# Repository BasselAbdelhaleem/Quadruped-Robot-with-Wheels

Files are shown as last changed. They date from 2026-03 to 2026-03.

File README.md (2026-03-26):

# 🤖 Quadruped-Robot-with-Wheels

> A four-legged robot with mecanum wheels at its feet — combining the terrain adaptability of legged locomotion with the speed and efficiency of wheeled drive.

<div align="center">
  <table style="width: 100%;">
    <tr>
      <td style="width: 60%; vertical-align: top;">
        
      </td>
      <td style="width: 40%; vertical-align: top;">
        
      </td>
    </tr>
  </table>
</div>

---

## 🧠 What Is This?

This is a custom-designed and fabricated quadruped robot that replaces the conventional foot end-effector with **mecanum wheels** — enabling both legged locomotion over uneven terrain and omnidirectional wheeled movement on flat surfaces. The robot is designed to be fully **modular**, with any component replaceable without modification to surrounding parts, making it ideal for research and iterative development.

Inspired by industry platforms like **Swiss-Mile (ETH Zurich)** and **Spot (Boston Dynamics)**, QuadWheel was built from the ground up using accessible materials and manufacturing methods — proving that advanced robot design is achievable outside of well-funded labs.

This project covers the complete hardware lifecycle — from concept and CAD to fabrication, assembly, and embedded low-level motor control.

---

## 🎥 Demo

<table style="width: 100%;">
  <tr>
    <td style="width: 33%; vertical-align: top;">
      <video src="https://github.com/user-attachments/assets/62846b2c-08e2-43ef-a53b-30cdd5eee27c"></video>
    </td>
    <td style="width: 33%; vertical-align: top;">
      <video src="https://github.com/user-attachments/assets/35af5436-f93d-4f27-a48a-da1c4396e53f"></video>
    </td>
    <td style="width: 33%; vertical-align: top;">
      <video src="https://github.com/user-attachments/assets/56d87e05-a18e-4513-a69d-81bef750ae9e"></video>
    </td>
  </tr>
</table>

---

## ✨ Key Features

- **Leg-wheel hybrid locomotion** — mecanum wheels as end-effectors enable both legged walking and omnidirectional rolling
- **Novel knee mechanism** — hip-mounted motor drives the knee via a lead screw, minimizing leg inertia and power consumption
- **3 DOF per leg** — hip abduction/adduction, hip flexion/extension, and knee flexion/extension
- **Incremental encoder feedback** — custom-designed optical encoder wheels on each joint for position and speed sensing
- **Modular architecture** — every subsystem (leg, motor hub, wheel bracket) is independently replaceable
- **Multi-material construction** — aluminum frame and structural links with 3D-printed enclosures and encoder components
- **Low-level stepper motor control** — closed-loop position and speed control via Arduino

---

## 🏗️ System Architecture

```
┌──────────────────────────────────────────────┐
│         HIGH-LEVEL CONTROL  (Future)         │
│   Gait Planning · Navigation · Vision        │
└───────────────────┬──────────────────────────┘
                    │ Serial / Communication
┌───────────────────▼──────────────────────────┐
│        LOW-LEVEL CONTROL  (Arduino)          │
│  Stepper Control · Encoder Feedback · PWM    │
└───────────────────┬──────────────────────────┘
                    │
┌───────────────────▼──────────────────────────┐
│              ACTUATORS & SENSORS             │
│  12× Stepper Motors · Optical Encoders       │
│  4× DC Wheel Motors · Motor Drivers          │
└──────────────────────────────────────────────┘
```

---

## 🔧 Hardware

### Platform Overview

| Property | Value |
|---|---|
| **Locomotion Type** | Leg-Wheel Hybrid |
| **Legs** | 4 |
| **DOF per Leg** | 3 (ab/ad + hip fl/ex + knee fl/ex) |
| **Total Joint Motors** | 12 × NEMA 17 Stepper |
| **Wheel Motors** | 4 × High-RPM DC Motor |
| **End Effector** | 120mm Mecanum Wheel |
| **Total Weight** | ~6 kg |
| **Max Leg Extension** | 665 mm |

### Mechanical Structure

#### Body
The chassis consists of an **aluminum square tube frame** (20mm × 20mm × 2mm wall) providing structural rigidity while keeping weight low. 3D-printed protective plates enclose the body and mount the legs, while a central electronics carriage houses all control hardware behind a removable cover for easy access.

| Body Component | Material | Quantity |
|---|---|---|
| Main frame tubes | Aluminum (2mm wall) | 10 |
| Protective side plates | 3D-printed PLA | 4 |
| Electronics carriage | 3D-printed PLA | 1 |
| Face plates | 3D-printed PLA | 2 |

#### Leg Design

Each leg has five major subsystems:

**1. Hip Joint (ab/ad) — Fixed Motor Hub**
Mounts the leg to the body and enables lateral swing. Houses the optical encoder disk and speed sensor pair.

**2. Hip Joint (fl/ex) — Rotating Motor Hub**
Drives the leg forward and backward. Coupled to the fixed motor hub via a D-shaft coupler, with a bearing support on the body side for smooth, supported rotation.

**3. Knee Mechanism — Lead Screw Drive**
A stepper motor at the hip rotates a lead screw which drives a linear slider along the upper leg. Two connecting plates link the slider to the lower leg, converting linear motion into knee rotation. This design keeps motor mass close to the hip pivot, **minimizing leg inertia** — the same approach used in Spot and Mini Cheetah.

```
Motor (rotation) → Lead Screw → Slider (linear) → Connecting Plates → Knee (rotation)
```

**4. Upper Leg Frame**
Four aluminum plates in a hollow truss pattern — strong under bending but material-efficient. Mounts the linear bearing block (for the slider) and pivots the lower leg.

**5. Lower Leg + Wheel Assembly**
An aluminum rod with a slotted profile that accepts:
- **Wheel bracket** — U-shaped plate holding the mecanum wheel on a bearing-supported rod
- **Wheel motor hub** — Houses a high-RPM DC motor; slides along the slot to tension the drive belt

The wheel motor drives the mecanum wheel via a **pulley-and-belt transmission**, keeping the motor mass on the leg body rather than at the foot — again minimizing rotational inertia.

### Mecanum Wheels

Mecanum wheels replace the conventional foot, providing **two degrees of freedom from a single motor**. By coordinating all four wheels, the robot can move forward, sideways, diagonally, or rotate in place — dramatically improving mobility on flat surfaces.

The wheel design was adapted from an open-source model and modified:
- Diameter scaled from 80mm → **120mm** for the robot's size
- Roller pin diameter changed from 3mm → **5mm** for local availability
- Mounting interface redesigned for belt-driven rod (rather than direct motor shaft)

```
Wheel directions achievable:
  Forward / Backward / Left / Right
  Clockwise / Anticlockwise rotation
  Diagonal movement in all directions
```

### Motor Selection & Gearbox

**Torque analysis (worst-case scenarios):**

| Scenario | Motor | Required Torque |
|---|---|---|
| Lifting leg (COM at knee) | Hip fl/ex | **6.23 Nm** |
| Lifting body with four legs | Knee | 3.5 Nm |
| Carrying body on two legs | Hip ab/ad | 1.91 Nm |

No single off-the-shelf motor available locally met the 6.23 Nm requirement. After evaluating DC, stepper, and brushless options across torque, size, weight, and bidirectional driver availability, **NEMA 17 stepper motors** were selected as the best balance — with a **1:15 planetary gearbox** added to reach the required output torque with a 1.2× safety factor.

| Motor | Max Torque | Speed | Count |
|---|---|---|---|
| NEMA 17 Stepper + 1:15 Gearbox | ~7.5 Nm (output) | — | 12 (joints) |
| High-RPM DC Motor | — | High | 4 (wheels) |

### Encoder Design

Custom **incremental optical encoders** were designed and 3D-printed for each joint motor:

- An encoder disk with **evenly spaced slots** (35mm diameter) mounts on the motor shaft
- Two photoelectric speed sensors are positioned on the disk at a **5° phase offset** to detect both speed and direction of rotation
- The quadrature signal (A/B channels) is read by the Arduino to compute joint position and velocity

This was a deliberate design challenge — servo motors with built-in encoders were intentionally avoided to demonstrate proficiency with raw actuator control.

### Manufacturing Methods

| Process | Applied To |
|---|---|
| **Welding** | Aluminum frame assembly |
| **Laser Cutting** | Side plates, top/bottom plates, connecting plates, encoder disks, wheel bracket |
| **Lathe (turning)** | Slider body, lower leg, wheel bracket neck |
| **Milling** | Slots, holes, flats on lower leg and slider |
| **3D Printing** | Covers, motor hubs, bearing extensions, encoder disks, mecanum rollers |
| **Bending** | Upper leg top/bottom plates, wheel bracket plate |

---

## 💻 Low-Level Control (Arduino)

### Stepper Motor Control

Each of the 12 NEMA 17 stepper motors is driven via a dedicated **stepper motor driver**. The Arduino generates step and direction signals to command precise angular positions.

- **Open-loop stepping** for commanded position targets
- **Closed-loop speed regulation** using encoder feedback to verify actual joint velocity
- Step resolution tunable via microstepping settings on the driver

### Encoder Feedback

The custom incremental encoders produce quadrature (A/B) pulse trains. The Arduino reads these via **interrupt-driven routines** for accurate, low-latency position and velocity estimation:

```cpp
// Quadrature decoding — direction from phase relationship
void encoderISR() {
  int a = digitalRead(ENC_A);
  int b = digitalRead(ENC_B);
  if (a == b) encoderCount++;
  else        encoderCount--;
}
```

Joint angle is tracked by counting encoder pulses and mapping to degrees using the disk's slot count.

### Motor Driver Interfacing

Each stepper driver receives:
- `STEP` — pulse per microstep
- `DIR` — rotation direction
- `EN` — enable/disable motor hold torque

The DC wheel motors are driven via separate motor drivers using PWM speed control and direction pins.

---

## 📐 Kinematics Overview

Each leg has 3 active joints providing a 3D workspace:

| Joint | DOF | Motion |
|---|---|---|
| Hip ab/ad | Rotation about body axis | Swings leg laterally |
| Hip fl/ex | Rotation about transverse axis | Swings leg forward/backward |
| Knee fl/ex | Rotation about transverse axis | Extends/retracts lower leg |

**Creeping gait** (statically stable): legs raised and lowered sequentially — at least 3 legs always on the ground. This is the planned initial gait for higher-level control implementation.

---

## 📁 Repository Structure

```
QuadWheel/
├── cad/
│   ├── body/                   # Body frame, covers, electronics carriage
│   ├── leg/                    # Upper leg, lower leg, slider, connecting plates
│   ├── wheel/                  # Mecanum wheel, bracket, motor hub
│   ├── encoder/                # Encoder disk, motor hub designs
│   └── gearbox/                # Modified 1:15 planetary gearbox
├── code/
│   ├── 2LegControl/            # Full leg control of 2 of the 4 legs
│   ├── CL_Leg_Control/         # Full closed loop leg control
│   └── DC/                     # DC motor control for the wheels
│   └── inverse_kinematics/     # Testing high level control for the leg inverse kinematics
│   └── master_writer/          # Communication between master board and slave boards
├── docs/
│   └── thesis.pdf              # Full design & fabrication documentation
├── engineering_drawings/       # Full dimensioned drawings for all parts
├── media/                      # Photos, videos, demo footage
└── README.md
```

---

## 🚀 Getting Started

### Hardware Requirements

- 12× NEMA 17 Stepper Motor + 1:15 Gearbox
- 12× Stepper Motor Driver (e.g., A4988 or DRV8825)
- 4× High-RPM DC Motor
- 4× DC Motor Driver
- Arduino Mega (recommended for pin count)
- 24× Photoelectric Speed Sensors (2 per joint)
- Custom encoder disks (3D print from `/cad/encoder/`)

### Software Setup

```bash
# Clone the repository
git clone https://github.com/yourusername/QuadWheel.git
cd QuadWheel/arduino

# Open in Arduino IDE
# Upload stepper_control/stepper_control.ino to your Arduino
```

### Running Joint Control

```cpp
// Example: Command hip flexion joint to 45 degrees
setJointAngle(HIP_FLEX_FL, 45.0);

// Example: Read current joint position from encoder
float angle = getJointAngle(HIP_FLEX_FL);
```

---

## 🔮 Future Work

The hardware and low-level firmware provide a solid foundation. Planned next steps:

- **Gait controller** — implement creeping (statically stable) and trotting gaits
- **Inverse kinematics** — foot-space to joint-space mapping for trajectory following
- **High-level autonomy** — integrate a single-board computer (Raspberry Pi / Jetson) for navigation
- **Brushless motor upgrade** — replace steppers with bidirectional brushless motors for higher power density
- **TPU roller replacement** — reprint mecanum wheel rollers in flexible filament for better grip
- **Sensor integration** — add IMU for body orientation, depth camera for terrain perception

---

## 🧩 Skills Demonstrated

| Domain | Demonstrated Skills |
|---|---|
| **Mechanical Design** | 3-DOF leg kinematics, lead-screw knee mechanism, belt-drive transmission, modular assembly |
| **CAD & Engineering Drawing** | Full robot CAD, toleranced engineering drawings for every custom part |
| **Manufacturing** | Welding, laser cutting, CNC lathe, milling, 3D printing — end-to-end fabrication |
| **Embedded Systems** | Arduino stepper control, quadrature encoder decoding, interrupt-driven ISRs |
| **Actuator Selection** | Torque analysis, gear ratio calculation, motor benchmarking under real constraints |
| **System Design** | Modular architecture for research-oriented iterative development |

---

## 📄 Documentation

The full design rationale, torque calculations, material selection, and fabrication process are documented in the thesis paper:

📄 [`docs/thesis.pdf`](docs/thesis.pdf) — *Design and Implementation of Quadruped with Wheels*, GUC Mechatronics Engineering, 2023

---

## 👤 Author

**Bassel Khaled Abdelhaleem**
Mechatronics Engineering — German University in Cairo (GUC)
Supervised by: Assoc. Prof. Dr. Eng. Amir Roushdy

📧 your.email@example.com
🔗 [LinkedIn](https://linkedin.com/in/yourprofile)

---

## 📄 License

This project is licensed under the MIT License — see [LICENSE](LICENSE) for details.

---

<p align="center">
  <i>Designed from scratch. Fabricated by hand. Driven by curiosity.</i>
</p>

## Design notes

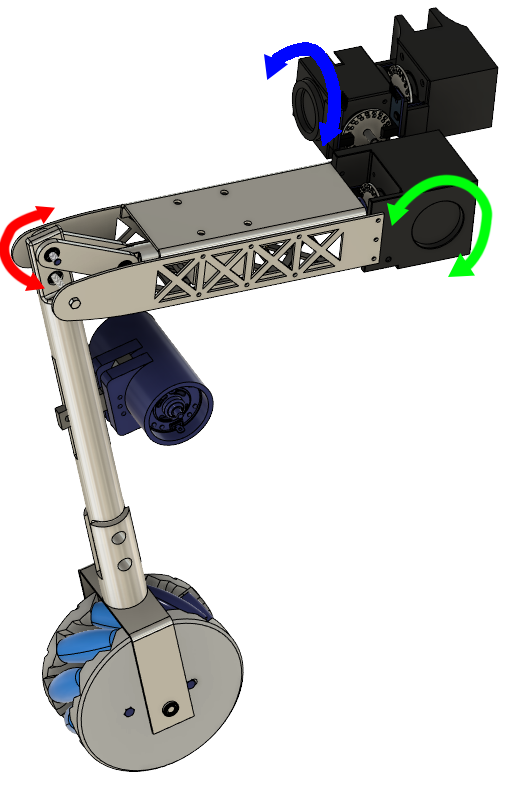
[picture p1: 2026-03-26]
media/Leg Model with motion arrows.png

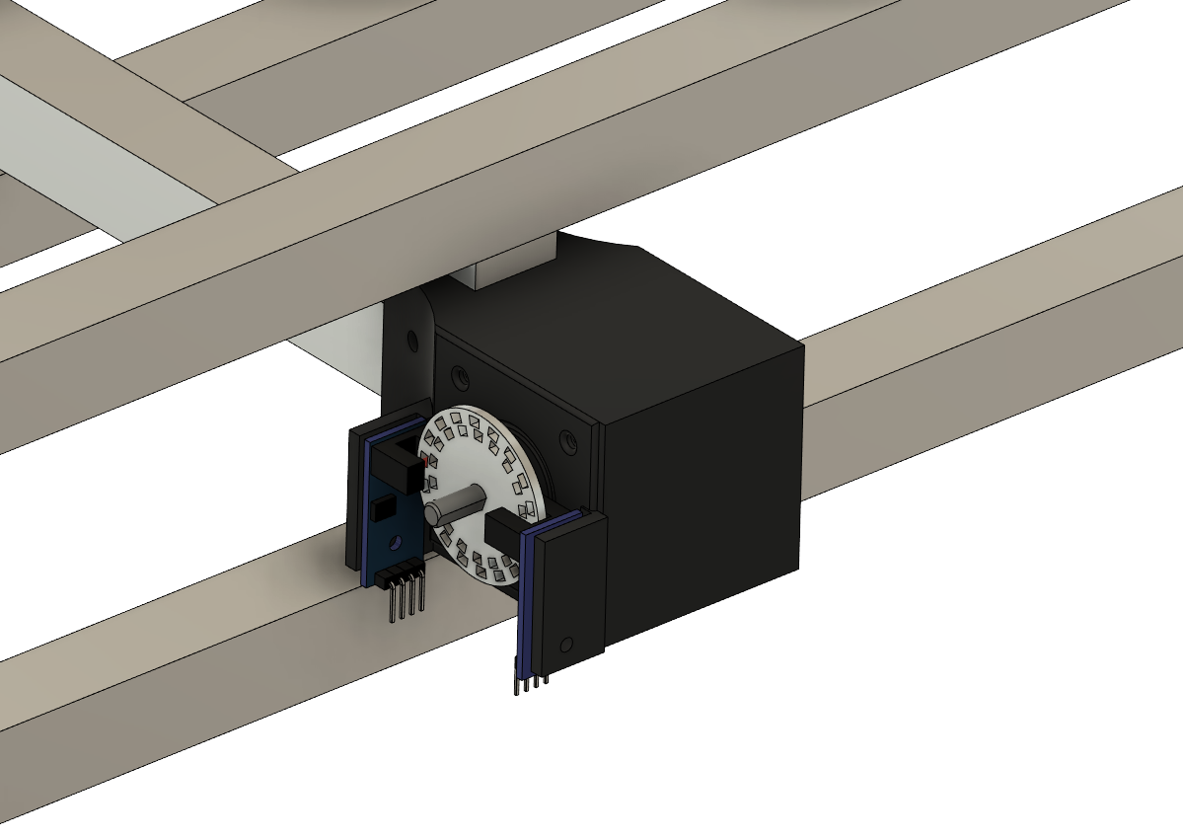
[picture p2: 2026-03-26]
media/Fixed Motor hub on body.png

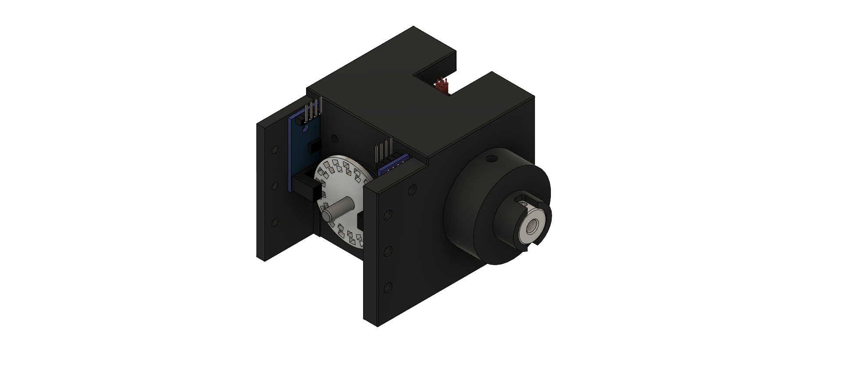
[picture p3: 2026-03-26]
media/Knee Motor Hub new.png

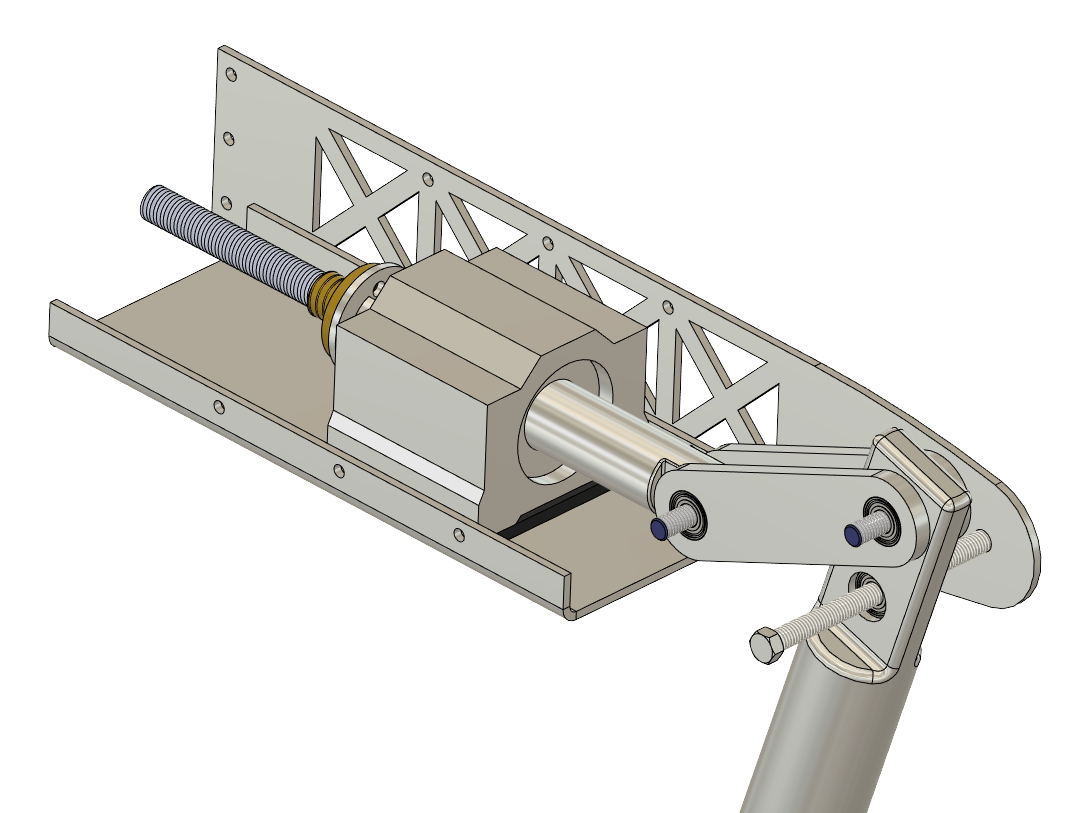
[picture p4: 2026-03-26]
media/Connecting Plates.png

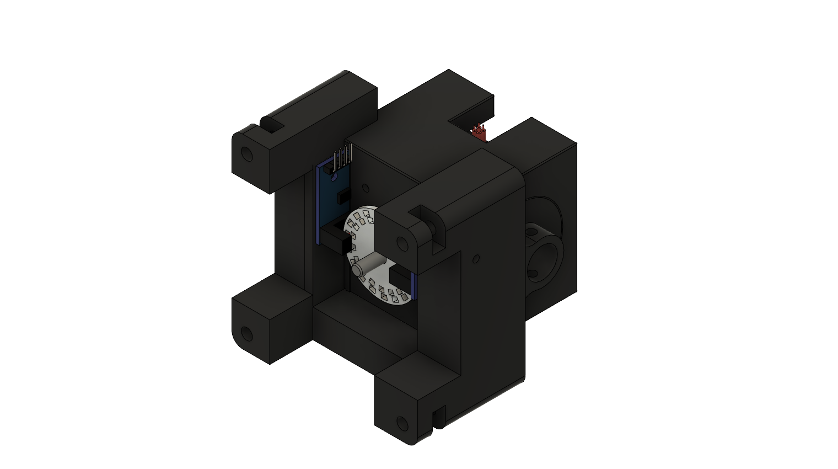
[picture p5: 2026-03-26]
media/Rotating Motor Hub new.png

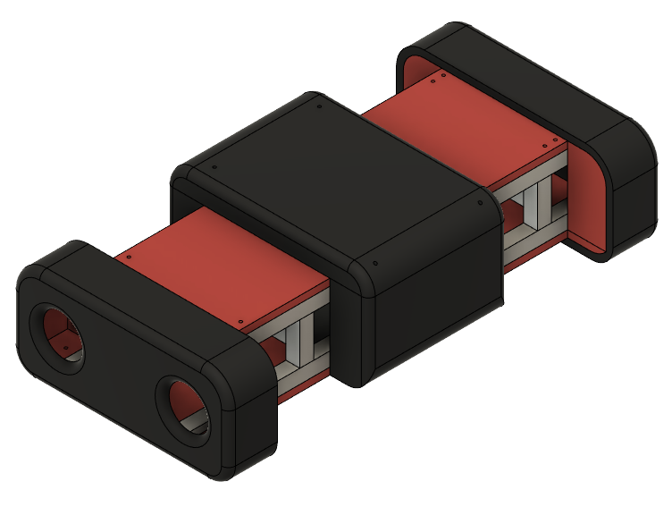
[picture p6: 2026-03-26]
media/Body.png

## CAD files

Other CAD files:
cad/_8-mm lead screw.1c959d5e-ae82-4d65-a514-8b0826073087.f3d
cad/_8mm Lead Screw.d66c99ec-897a-4300-bc53-3debbe2a3609.f3d
cad/_Aluminum Square Tube 140mm.e856f826-5169-4751-9446-e42fab014422.f3d
cad/_Aluminum Square Tube 600mm.9d08fe10-a695-4359-8446-904a571cda24.f3d
cad/_Aluminum Square Tube 60mm.18603a37-9614-456d-951d-5e2553b5a8b8.f3d
cad/_Back Left Leg.a9f00470-0ef0-4690-a3cf-9215a9c23bdc.f3d
cad/_Back Right Leg.691853e6-ca59-419d-a8fc-fe1a00d16451.f3d
cad/_Bearing 61904.1ed075eb-d7d1-4e55-98bb-6b850e03c20e.f3d
cad/_Bearing 628_5-2Z.6bdbf784-737e-40b5-bb04-947494ef0179.f3d
cad/_Body.7ab0c087-588a-4772-b4b6-61f81eb7d17c.f3d
cad/_Coupler 5-8.18f0973a-a07b-4757-b95f-701b0c2533d9.f3d
cad/_Encoder Wheel.eb9523d5-e484-4a40-b553-a28b88c10ead.f3d
cad/_F249 sensor v2.d0049eca-ee8b-4d05-afa8-f4fc4885895e.f3d
cad/_Fixed Motor Hub.4b5598e1-1b2e-4186-93a6-b51d7441d166.f3d
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

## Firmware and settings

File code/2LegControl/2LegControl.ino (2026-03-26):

/*This code controls the two front legs*/

#include <TMCStepper.h>
#include <AccelStepper.h>
#include <Arduino.h>
#include <RotaryEncoder.h>
#include <SoftwareSerial.h>

// right front leg steppers
// knee stepper parameters
#define STEP_RK_DIR_PIN          22 // Direction
#define STEP_RK_STEP_PIN         23 // Step
#define STEP_RK_SW_SCK           24 // Software Slave Clock (SCK)
#define STEP_RK_SW_TX            25 // SoftwareSerial transmit pin
#define STEP_RK_SW_RX            26 // SoftwareSerial receive pin

// rotating stepper parameters
#define STEP_RR_DIR_PIN          27 // Direction
#define STEP_RR_STEP_PIN         28 // Step
#define STEP_RR_SW_SCK           29 // Software Slave Clock (SCK)
#define STEP_RR_SW_TX            30 // SoftwareSerial transmit pin
#define STEP_RR_SW_RX            31 // SoftwareSerial receive pin

// fixed parameters
#define STEP_RF_DIR_PIN          32 // Direction
#define STEP_RF_STEP_PIN         33 // Step
#define STEP_RF_SW_SCK           34 // Software Slave Clock (SCK)
#define STEP_RF_SW_TX            35 // SoftwareSerial transmit pin
#define STEP_RF_SW_RX            36 // SoftwareSerial receive pin

// left front leg steppers
// knee stepper parameters
#define STEP_LK_DIR_PIN          37 // Direction
#define STEP_LK_STEP_PIN         38 // Step
#define STEP_LK_SW_SCK           39 // Software Slave Clock (SCK)
#define STEP_LK_SW_TX            40 // SoftwareSerial transmit pin
#define STEP_LK_SW_RX            41 // SoftwareSerial receive pin

// rotating stepper parameters
#define STEP_LR_DIR_PIN          47 // Direction
#define STEP_LR_STEP_PIN         48 // Step
#define STEP_LR_SW_SCK           49 // Software Slave Clock (SCK)
#define STEP_LR_SW_TX            50 // SoftwareSerial transmit pin
#define STEP_LR_SW_RX            51 // SoftwareSerial receive pin

// fixed stepper parameters
#define STEP_LF_DIR_PIN          42 // Direction
#define STEP_LF_STEP_PIN         43 // Step
#define STEP_LF_SW_SCK           44 // Software Slave Clock (SCK)
#define STEP_LF_SW_TX            45 // SoftwareSerial transmit pin
#define STEP_LF_SW_RX            46 // SoftwareSerial receive pin

#define R_SENSE 0.11f // Internal Sense Resistor controls the max RMS current
#define stepsPerRevolution 200 // Motor steps per rev (1.8deg) // 80
#define minPos -1*stepsPerRevolution
#define maxPos stepsPerRevolution
int posInLK = 0;
int posInLR = 0;
int posInLF = 0;
int posInRK = 0;
int posInRR = 0;
int posInRF = 0;
                     
TMC2208Stepper driverRK = TMC2208Stepper(STEP_RK_SW_RX, STEP_RK_SW_TX, R_SENSE); // Contsruct driver1
AccelStepper stepperRK(AccelStepper::DRIVER, STEP_RK_STEP_PIN, STEP_RK_DIR_PIN); // Construct motor1

TMC2208Stepper driverRR = TMC2208Stepper(STEP_RR_SW_RX, STEP_RR_SW_TX, R_SENSE); // Contsruct driver2
AccelStepper stepperRR(AccelStepper::DRIVER, STEP_RR_STEP_PIN, STEP_RR_DIR_PIN); // Construct motor2

TMC2208Stepper driverRF = TMC2208Stepper(STEP_RF_SW_RX, STEP_RF_SW_TX, R_SENSE); // Contsruct driver3
AccelStepper stepperRF(AccelStepper::DRIVER, STEP_RF_STEP_PIN, STEP_RF_DIR_PIN); // Construct motor3

TMC2208Stepper driverLK = TMC2208Stepper(STEP_LK_SW_RX, STEP_LK_SW_TX, R_SENSE); // Contsruct driver1
AccelStepper stepperLK(AccelStepper::DRIVER, STEP_LK_STEP_PIN, STEP_LK_DIR_PIN); // Construct motor1

TMC2208Stepper driverLR = TMC2208Stepper(STEP_LR_SW_RX, STEP_LR_SW_TX, R_SENSE); // Contsruct driver2
AccelStepper stepperLR(AccelStepper::DRIVER, STEP_LR_STEP_PIN, STEP_LR_DIR_PIN); // Construct motor2

TMC2208Stepper driverLF = TMC2208Stepper(STEP_LF_SW_RX, STEP_LF_SW_TX, R_SENSE); // Contsruct driver3
AccelStepper stepperLF(AccelStepper::DRIVER, STEP_LF_STEP_PIN, STEP_LF_DIR_PIN); // Construct motor3

// Left leg encoders
// Encoder Knee
#define EncoderLK_PIN1 A0
#define EncoderLK_PIN2 A1

RotaryEncoder *encoderLK = nullptr;
void checkPositionLK()
{
  encoderLK->tick(); // just call tick() to check the state.
}

// Encoder Rotating
#define EncoderLR_PIN1 A2
#define EncoderLR_PIN2 A3

RotaryEncoder *encoderLR = nullptr;
void checkPositionLR()
{
  encoderLR->tick(); // just call tick() to check the state.
}

// Encoder Fixed
#define EncoderLF_PIN1 A4
#define EncoderLF_PIN2 A5

RotaryEncoder *encoderLF = nullptr;
void checkPositionLF()
{
  encoderLF->tick(); // just call tick() to check the state.
}

// Right leg encoders
// Encoder Knee
#define EncoderRK_PIN1 A6
#define EncoderRK_PIN2 A7

RotaryEncoder *encoderRK = nullptr;
void checkPositionRK()
{
  encoderRK->tick(); // just call tick() to check the state.
}

// Encoder Rotating
#define EncoderRR_PIN1 A8
#define EncoderRR_PIN2 A9

RotaryEncoder *encoderRR = nullptr;
void checkPositionRR()
{
  encoderRR->tick(); // just call tick() to check the state.
}

// Encoder Fixed
#define EncoderRF_PIN1 A10
#define EncoderRF_PIN2 A11

RotaryEncoder *encoderRF = nullptr;
void checkPositionRF()
{
  encoderRF->tick(); // just call tick() to check the state.
}

void setup()
{
  Serial.begin(115200);
  while(!Serial);
  Serial.println("Start...");

  // Left leg stepper
  // Stepper knee settings
  driverLK.begin();             // Initiate pins and registeries
  driverLK.rms_current(1200);    // Set stepper current to 600mA. The command is the same as command driver.setCurrent(600, 0.11, 0.5);
  driverLK.pwm_autoscale(true);
  driverLK.microsteps(0);
  stepperLK.setMaxSpeed(4000);
  stepperLK.setAcceleration(80000);
  stepperLK.setPinsInverted(false, false, true); // Invert Enable pin
  stepperLK.enableOutputs();

  // Stepper rotating settings
  driverLR.begin();             // Initiate pins and registeries
  driverLR.rms_current(1200);    // Set stepper current to 600mA. The command is the same as command driver.setCurrent(600, 0.11, 0.5);
  driverLR.pwm_autoscale(true);
  driverLR.microsteps(0);
  stepperLR.setMaxSpeed(4000);
  stepperLR.setAcceleration(80000);
  stepperLR.setPinsInverted(false, false, true); // Invert Enable pin
  stepperLR.enableOutputs();

  // Stepper fixed settings
  driverLF.begin();             // Initiate pins and registeries
  driverLF.rms_current(1200);    // Set stepper current to 600mA. The command is the same as command driver.setCurrent(600, 0.11, 0.5);
  driverLF.pwm_autoscale(true);
  driverLF.microsteps(0);
  stepperLF.setMaxSpeed(4000);
  stepperLF.setAcceleration(80000);
  stepperLF.setPinsInverted(false, false, true); // Invert Enable pin
  stepperLF.enableOutputs();

  // Right leg stepper
  // Stepper knee settings
  driverRK.begin();             // Initiate pins and registeries
  driverRK.rms_current(1200);    // Set stepper current to 600mA. The command is the same as command driver.setCurrent(600, 0.11, 0.5);
  driverRK.pwm_autoscale(true);
  driverRK.microsteps(0);
  stepperRK.setMaxSpeed(4000);
  stepperRK.setAcceleration(80000);
  stepperRK.setPinsInverted(false, false, true); // Invert Enable pin
  stepperRK.enableOutputs();

  // Stepper rotating settings
  driverRR.begin();             // Initiate pins and registeries
  driverRR.rms_current(1200);    // Set stepper current to 600mA. The command is the same as command driver.setCurrent(600, 0.11, 0.5);
  driverRR.pwm_autoscale(true);
  driverRR.microsteps(0);
  stepperRR.setMaxSpeed(4000);
  stepperRR.setAcceleration(80000);
  stepperRR.setPinsInverted(false, false, true); // Invert Enable pin
  stepperRR.enableOutputs();

  // Stepper fixed settings
  driverRF.begin();             // Initiate pins and registeries
  driverRF.rms_current(1200);    // Set stepper current to 600mA. The command is the same as command driver.setCurrent(600, 0.11, 0.5);
  driverRF.pwm_autoscale(true);
  driverRF.microsteps(0);
  stepperRF.setMaxSpeed(4000);
  stepperRF.setAcceleration(80000);
  stepperRF.setPinsInverted(false, false, true); // Invert Enable pin
  stepperRF.enableOutputs();

  // Left leg encoders
  // Encoder knee settings
  encoderLK = new RotaryEncoder(EncoderLK_PIN1, EncoderLK_PIN2, RotaryEncoder::LatchMode::TWO03);
  attachInterrupt(digitalPinToInterrupt(EncoderLK_PIN1), checkPositionLK, CHANGE);
  attachInterrupt(digitalPinToInterrupt(EncoderLK_PIN2), checkPositionLK, CHANGE);

  // Encoder rotating settings
  encoderLR = new RotaryEncoder(EncoderLR_PIN1, EncoderLR_PIN2, RotaryEncoder::LatchMode::TWO03);
  attachInterrupt(digitalPinToInterrupt(EncoderLR_PIN1), checkPositionLR, CHANGE);
  attachInterrupt(digitalPinToInterrupt(EncoderLR_PIN2), checkPositionLR, CHANGE);

  // Encoder fixed settings
  encoderLF = new RotaryEncoder(EncoderLF_PIN1, EncoderLF_PIN2, RotaryEncoder::LatchMode::TWO03);
  attachInterrupt(digitalPinToInterrupt(EncoderLF_PIN1), checkPositionLF, CHANGE);
  attachInterrupt(digitalPinToInterrupt(EncoderLF_PIN2), checkPositionLF, CHANGE);

  // Right leg encoders
  // Encoder knee settings
  encoderRK = new RotaryEncoder(EncoderRK_PIN1, EncoderRK_PIN2, RotaryEncoder::LatchMode::TWO03);
  attachInterrupt(digitalPinToInterrupt(EncoderRK_PIN1), checkPositionRK, CHANGE);
  attachInterrupt(digitalPinToInterrupt(EncoderRK_PIN2), checkPositionRK, CHANGE);

  // Encoder rotating settings
  encoderRR = new RotaryEncoder(EncoderRR_PIN1, EncoderRR_PIN2, RotaryEncoder::LatchMode::TWO03);
  attachInterrupt(digitalPinToInterrupt(EncoderRR_PIN1), checkPositionRR, CHANGE);
  attachInterrupt(digitalPinToInterrupt(EncoderRR_PIN2), checkPositionRR, CHANGE);

  // Encoder fixed settings
  encoderRF = new RotaryEncoder(EncoderRF_PIN1, EncoderRF_PIN2, RotaryEncoder::LatchMode::TWO03);
  attachInterrupt(digitalPinToInterrupt(EncoderRF_PIN1), checkPositionRF, CHANGE);
  attachInterrupt(digitalPinToInterrupt(EncoderRF_PIN2), checkPositionRF, CHANGE);
}

void loop()
{
  int limit = 500;
  posInRK = map(analogRead(A13), 0, 1023, -limit, limit);
  posInRR = map(analogRead(A14), 0, 1023, -2000, 2000);
  posInRF = map(analogRead(A15), 0, 1023, -limit, limit);

  //Left leg Update
  //update encoderLK
  static int posLK = 0;
  encoderLK->tick();
  int newPosLK = ((encoderLK->getPosition())*(5.58));
  stepperLK.setCurrentPosition(newPosLK);
  //move stepperLK
  stepperLK.moveTo(posInLK);
  if(!inRange(stepperLK))
    stepperLK.run();

  //update encoderLR
  static int posLR = 0;
  encoderLR->tick();
  int newPosLR = ((encoderLR->getPosition())*(5.58));
  stepperLR.setCurrentPosition(newPosLR);
  //move stepperLR
  stepperLR.moveTo(posInLR);
  if(!inRange(stepperLR))
    stepperLR.run();

  //update encoderLF
  static int posLF = 0;
  encoderLF->tick();
  int newPosLF = ((encoderLF->getPosition())*(5.58));
  stepperLF.setCurrentPosition(newPosLF);
  //move stepperLF
  stepperLF.moveTo(posInLF);
  if(!inRange(stepperLF))
    stepperLF.run();

  //Right leg update
  //update encoderRK
  static int posRK = 0;
  encoderRK->tick();
  int newPosRK = ((encoderRK->getPosition())*(5.58));
  stepperRK.setCurrentPosition(newPosRK);
  //move stepperRK
  stepperRK.moveTo(posInRK);
  if(!inRange(stepperRK))
    stepperRK.run();

  //update encoderRR
  static int posRR = 0;
  encoderRR->tick();
  int newPosRR = ((encoderRR->getPosition())*(5.58));
  stepperRR.setCurrentPosition(newPosRR);
  //move stepperRR
  stepperRR.moveTo(posInRR);
  if(!inRange(stepperRR))
    stepperRR.run();

  //update encoderRF
  static int posRF = 0;
  encoderRF->tick();
  int newPosRF = ((encoderRF->getPosition())*(5.58));
  stepperRF.setCurrentPosition(newPosRF);
  //move stepperRF
  stepperRF.moveTo(posInRF);
  if(!inRange(stepperRF))
    stepperRF.run();

  Serial.print(stepperRK.distanceToGo());
  Serial.print(" ");
  Serial.print(stepperRR.distanceToGo());
  Serial.print(" ");
  Serial.println(stepperRF.distanceToGo());
}

/* This function increases stepper vibration
int encoderSet(RotaryEncoder *encoder, AccelStepper stepper, int pos)
{
  encoder->tick();
  int newPos = ((encoder->getPosition())*(5.58));
  if (pos != newPos)
    pos = newPos;
  stepper.setCurrentPosition(pos);
  return pos;
}
*/

bool inRange(AccelStepper stepper)
{
  return abs(stepper.distanceToGo())<=15;
}

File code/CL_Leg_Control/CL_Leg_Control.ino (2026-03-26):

#include <TMCStepper.h>
#include <AccelStepper.h>
#include <Arduino.h>
#include <RotaryEncoder.h>
#include <SoftwareSerial.h>

// Stepper1 parameters
#define STEP1_DIR_PIN          37 // Direction
#define STEP1_STEP_PIN         38 // Step
#define STEP1_SW_SCK           39 // Software Slave Clock (SCK)
#define STEP1_SW_TX            40 // SoftwareSerial transmit pin
#define STEP1_SW_RX            41 // SoftwareSerial receive pin

// Stepper2 parameters
#define STEP2_DIR_PIN          47 // Direction
#define STEP2_STEP_PIN         48 // Step
#define STEP2_SW_SCK           49 // Software Slave Clock (SCK)
#define STEP2_SW_TX            50 // SoftwareSerial transmit pin
#define STEP2_SW_RX            51 // SoftwareSerial receive pin

// Stepper3 parameters
//#define STEP3_EN_PIN           2 // Enable
#define STEP3_DIR_PIN          22 // Direction
#define STEP3_STEP_PIN         23 // Step
#define STEP3_SW_SCK           24 // Software Slave Clock (SCK)
#define STEP3_SW_TX            25 // SoftwareSerial transmit pin
#define STEP3_SW_RX            26 // SoftwareSerial receive pin
#define STEP3_SERIAL_PORT Serial3 // HardwareSerial port

#define R_SENSE 0.11f // Internal Sense Resistor controls the max RMS current
#define stepsPerRevolution 200 // Motor steps per rev (1.8deg) // 80
#define minPos -1*stepsPerRevolution
#define maxPos stepsPerRevolution
int posIn1 = 0;
int posIn2 = 0;
int posIn3 = 0;
                     
TMC2208Stepper driver1 = TMC2208Stepper(STEP1_SW_RX, STEP1_SW_TX, R_SENSE); // Contsruct driver1
AccelStepper stepper1(AccelStepper::DRIVER, STEP1_STEP_PIN, STEP1_DIR_PIN); // Construct motor1

TMC2208Stepper driver2 = TMC2208Stepper(STEP2_SW_RX, STEP2_SW_TX, R_SENSE); // Contsruct driver2
AccelStepper stepper2(AccelStepper::DRIVER, STEP2_STEP_PIN, STEP2_DIR_PIN); // Construct motor2

TMC2208Stepper driver3 = TMC2208Stepper(STEP3_SW_RX, STEP3_SW_TX, R_SENSE); // Contsruct driver3
AccelStepper stepper3(AccelStepper::DRIVER, STEP3_STEP_PIN, STEP3_DIR_PIN); // Construct motor3

// Encoder1
#define Encoder1_PIN1 A0
#define Encoder1_PIN2 A1

RotaryEncoder *encoder1 = nullptr;
void checkPosition1()
{
  encoder1->tick(); // just call tick() to check the state.
}

// Encoder2
#define Encoder2_PIN1 A2
#define Encoder2_PIN2 A3

RotaryEncoder *encoder2 = nullptr;
void checkPosition2()
{
  encoder2->tick(); // just call tick() to check the state.
}

// Encoder3
#define Encoder3_PIN1 A4
#define Encoder3_PIN2 A5

RotaryEncoder *encoder3 = nullptr;
void checkPosition3()
{
  encoder3->tick(); // just call tick() to check the state.
}

void setup()
{
  Serial.begin(115200);
  while(!Serial);
  Serial.println("Start...");

  // Stepper1 settings
  driver1.begin();             // Initiate pins and registeries
  driver1.rms_current(1200);    // Set stepper current to 600mA. The command is the same as command driver.setCurrent(600, 0.11, 0.5);
  //driver1.en_pwm_mode(1);      // Enable extremely quiet stepping
  driver1.pwm_autoscale(true);
  driver1.microsteps(0);
  stepper1.setMaxSpeed(4000);
  stepper1.setAcceleration(80000);
  //stepper1.setEnablePin(STEP1_EN_PIN);
  stepper1.setPinsInverted(false, false, true); // Invert Enable pin
  stepper1.enableOutputs();

  // Stepper2 settings
  driver2.begin();             // Initiate pins and registeries
  driver2.rms_current(1200);    // Set stepper current to 600mA. The command is the same as command driver.setCurrent(600, 0.11, 0.5);
  driver2.pwm_autoscale(true);
  driver2.microsteps(0);
  stepper2.setMaxSpeed(4000);
  stepper2.setAcceleration(80000);
  stepper2.setPinsInverted(false, false, true); // Invert Enable pin
  stepper2.enableOutputs();

  // Stepper3 settings
  driver3.begin();             // Initiate pins and registeries
  driver3.rms_current(1200);    // Set stepper current to 600mA. The command is the same as command driver.setCurrent(600, 0.11, 0.5);
  //driver3.en_pwm_mode(1);      // Enable extremely quiet stepping
  driver3.pwm_autoscale(true);
  driver3.microsteps(0);
  stepper3.setMaxSpeed(4000);
  stepper3.setAcceleration(80000);
  //stepper3.setEnablePin(STEP3_EN_PIN);
  stepper3.setPinsInverted(false, false, true); // Invert Enable pin
  stepper3.enableOutputs();

  // Encoder1 settings
  encoder1 = new RotaryEncoder(Encoder1_PIN1, Encoder1_PIN2, RotaryEncoder::LatchMode::TWO03);
  attachInterrupt(digitalPinToInterrupt(Encoder1_PIN1), checkPosition1, CHANGE);
  attachInterrupt(digitalPinToInterrupt(Encoder1_PIN2), checkPosition1, CHANGE);

  // Encoder2 settings
  encoder2 = new RotaryEncoder(Encoder2_PIN1, Encoder2_PIN2, RotaryEncoder::LatchMode::TWO03);
  attachInterrupt(digitalPinToInterrupt(Encoder2_PIN1), checkPosition2, CHANGE);
  attachInterrupt(digitalPinToInterrupt(Encoder2_PIN2), checkPosition2, CHANGE);

  // Encoder3 settings
  encoder3 = new RotaryEncoder(Encoder3_PIN1, Encoder3_PIN2, RotaryEncoder::LatchMode::TWO03);
  attachInterrupt(digitalPinToInterrupt(Encoder3_PIN1), checkPosition3, CHANGE);
  attachInterrupt(digitalPinToInterrupt(Encoder3_PIN2), checkPosition3, CHANGE);
}

void loop()
{
  posIn1 = map(analogRead(A13), 0, 1023, -500, 500);
  posIn2 = map(analogRead(A14), 0, 1023, -500, 500);
  posIn3 = map(analogRead(A15), 0, 1023, -500, 500);

  //update encoder1
  static int pos1 = 0;
  encoder1->tick();
  int newPos1 = ((encoder1->getPosition())*(5.58));
  stepper1.setCurrentPosition(newPos1);

  //move stepper 1
  stepper1.moveTo(posIn1);
  if(!inRange(stepper1))
    stepper1.run();

  //update encoder2
  static int pos2 = 0;
  encoder2->tick();
  int newPos2 = ((encoder2->getPosition())*(5.58));
  stepper2.setCurrentPosition(newPos2);

  //move stepper 2
  stepper2.moveTo(posIn2);
  if(!inRange(stepper2))
    stepper2.run();

  //update encoder3
  static int pos3 = 0;
  encoder3->tick();
  int newPos3 = ((encoder3->getPosition())*(5.58));
  stepper3.setCurrentPosition(newPos3);

  //move stepper 3
  stepper3.moveTo(posIn3);
  if(!inRange(stepper3))
    stepper3.run();

  Serial.print(stepper1.distanceToGo());
  Serial.print(" ");
  Serial.print(stepper2.distanceToGo());
  Serial.print(" ");
  Serial.println(stepper3.distanceToGo());
}

/* This function increases stepper vibration
int encoderSet(RotaryEncoder *encoder, AccelStepper stepper, int pos)
{
  encoder->tick();
  int newPos = ((encoder->getPosition())*(5.58));
  if (pos != newPos)
    pos = newPos;
  stepper.setCurrentPosition(pos);
  return pos;
}
*/

bool inRange(AccelStepper stepper)
{
  return abs(stepper.distanceToGo())<=15;
}
